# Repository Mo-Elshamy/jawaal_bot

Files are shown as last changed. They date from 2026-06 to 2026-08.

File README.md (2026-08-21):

# Jawbot Autonomous Mobile Robot (AMR)





## 1. Overview
Jawbot is a custom-built Autonomous Mobile Robot (AMR) designed around a differential drive kinematics system. It aims to bridge low-level microcontrollers (Raspberry Pi Pico) with high-level ROS 2 navigation stacks, providing a robust, extensible platform for research, education, and development of mobile robotics applications.

## 2. Key Features
- **Diff-Drive Kinematics:** Fully supported by the ROS 2 `diff_drive_controller` and `joint_state_broadcaster`.
- **Custom Hardware Interface:** Uses a custom `ros2_control` `SystemInterface` to communicate seamlessly with the microcontroller.
- **Real-Time Closed-Loop Control:** Dual-stage friction compensation (breakaway kick & kinetic assist) and PID velocity tracking executed deterministically on the Raspberry Pi Pico at 50Hz.
- **RPLiDAR A1 Integration:** Dedicated ROS 2 node setup for real-time 2D laser scan publishing (`/scan`).
- **2D SLAM & Map Localization:** Parameterized `slam_toolbox` mapping and `AMCL` particle filter localization for precise map-based pose estimation.
- **Nav2 Autonomous Navigation:** Full integration with ROS 2 Nav2 stack featuring Regulated Pure Pursuit, local/global costmaps, velocity smoother, and collision monitor.
- **Simulation Ready:** Full integration with Gazebo (Harmonic) for physics simulation and testing prior to hardware deployment.
- **Modular Architecture:** Packages are neatly decoupled, isolating hardware drivers from kinematics, localization, and navigation.

## 3. System Architecture Stack
Jawbot operates on a decoupled, full-stack architecture:

- **Hardware Layer:** Raspberry Pi Pico (Main MCU), L298N Motor Drivers, Quadrature Encoders, and RPLiDAR A1 M8. Handles real-time dual-stage friction compensation, interrupt-driven sensor tracking, and 2D laser range scanning.
- **Software Layer:** Runs on Ubuntu 24.04 with ROS 2 Jazzy. Manages high-level velocity commands (`cmd_vel`), TF trees, state publishing, EKF sensor fusion (50Hz), AMCL localization, `slam_toolbox` mapping, and Nav2 path execution (`velocity_smoother` & `collision_monitor`).
- **Control Bridge:** A robust, non-blocking ASCII Serial Protocol over `/dev/ttyACM0` connecting the Linux environment to the hardware.

*For a detailed deep-dive into the control architecture, firmware design, dual-stage friction compensation, and serial protocol, please see the [Control Architecture Documentation](jawbot_hardware/Control_Arc.md).*
*For step-by-step procedures on calibrating odometry (wheel radius, track width, encoder ticks) and IMU offsets (GY-87), please see the [Sensor & Odometry Calibration Guide](SENSOR_CALIBRATION.md).*
*For tuning guidelines, parameter definitions, and troubleshooting common navigation behaviors, please see the [Nav2 Calibration Guide](NAV2_CALIBRATION.md).*

## 4. Repository Structure
The project is divided into several focused ROS 2 packages:

- **`jawbot_description`**: Contains the URDF, Xacro macros, and 3D meshes defining the robot's physical properties.
- **`jawbot_hardware`**: The core C++ `ros2_control` hardware plugin, Linux serial communication drivers, firmware (`RobotJoint` dual-stage friction logic), and RPLiDAR launch configuration.
- **`jawbot_gazebo`**: Launch files and world definitions for Gazebo simulation.
- **`jawbot_bringup`**: Orchestrates the launch sequences, starting the robot state publisher, controller manager, and spawning controllers.
- **`jawbot_localization`**: Extended Kalman Filter (EKF) state estimation fusing raw IMU data and wheel odometry at 50Hz, plus standalone AMCL launch configurations.
- **`jawbot_navigation`**: Configuration files for ROS 2 Nav2, AMCL parameters, `slam_toolbox` params, navigation launch scripts, and saved maps.

## 5. Prerequisites & Dependencies
- **OS:** Ubuntu 24.04 LTS
- **ROS 2:** Jazzy Jalisco
- **Build Tool:** `colcon`
- **Dependencies:**
  - `ros2_control` & `ros2_controllers`
  - `robot_state_publisher`
  - `xacro`
  - `gazebo_ros_pkgs`
  - `robot_localization`
  - `rplidar_ros`
  - `slam_toolbox`
  - `nav2_bringup`
  - `nav2_amcl`
  - `nav2_map_server`
  - `nav2_lifecycle_manager`

### Hardware Requirements
- Host computer / SBC running Linux
- Raspberry Pi Pico (flashed with `jawbot_pico` firmware)
- USB Serial connection to the Pico (e.g., `/dev/ttyACM0`)

## 6. Simulation Deployment Guide

This section outlines how to set up, build, and run the robot in a simulated Gazebo environment on your local development machine.

### Step 1: Set Up Workspace & Clone Packages
```bash
mkdir -p ~/test_ws/src
cd ~/test_ws/src
# Clone the jawbot repository here
```

### Step 2: Install Dependencies
```bash
cd ~/test_ws
source /opt/ros/jazzy/setup.bash
rosdep install --from-paths src --ignore-src -r -y
```

### Step 3: Compile the Workspace
```bash
colcon build --symlink-install
```

### Step 4: Sourcing and Running the Simulation
```bash
source install/setup.bash
ros2 launch jawbot_gazebo gazebo.launch.py
```

### Teleoperation
To drive the robot in the simulation, open a new terminal and run:
```bash
source /opt/ros/jazzy/setup.bash
ros2 run teleop_twist_keyboard teleop_twist_keyboard
```

## 7. Real Hardware Deployment Guide (Wireless / Pi Mode)

This section outlines how to deploy, compile, and run the production robotics stack directly on the robot's onboard Single Board Computer (SBC) over a wireless network link.

### Prerequisites
* The SBC must be powered, connected to the same local Wi-Fi subnet as your development laptop, and have SSH enabled.
* The low-level microcontroller (e.g., Pi Pico, ESP32) must be physically attached to the SBC via a USB data cable.
* ROS 2 must already be natively installed on the SBC operating system.

---

### Step 1: Establish Remote Connection (SSH)
Open a terminal window on your laptop and log into the robot’s wireless terminal interface. Replace `<username>` and `<hostname>` with your robot's configured credentials:

```bash
ssh <username>@<hostname>.local
# (Alternatively, connect using the robot's direct IP address: ssh <username>@<ip_address>)

```

### Step 2: Set Up Workspace & Clone Packages

Create a dedicated developer workspace, navigate to its source folder, and pull down your robot controller repositories:

```bash
# Create the workspace directory structure
mkdir -p ~/robot_ws/src
cd ~/robot_ws/src

# Clone your robot code repositories
git clone <your_repository_git_url> .

```

### Step 3: Configure Hardware Access Permissions

Linux secures hardware serial lines by default. Grant your user account permanent permission to read and write data over the physical USB serial port interfaces:

```bash
# Add the active user to the dialout hardware communication group
sudo usermod -aG dialout $USER

# Force-apply the group updates without requiring a system reboot
newgrp dialout
# (Verify your microcontroller is registered by running ls /dev/ttyACM* or ls /dev/ttyUSB*)

```

### Step 4: Resolve Dependencies Automatically

Scan the cloned repository package definitions (`package.xml`) and pull down any missing drivers, middleware, or operational plugins required by the hardware control loops:

```bash
cd ~/robot_ws
sudo apt update
rosdep update
rosdep install --from-paths src --ignore-src -y --rosdistro $ROS_DISTRO

```

### Step 5: Compile the Workspace

Compile the package nodes and hardware interface plugins directly on the single-board computer architecture. We use symbolic link maps to allow modification of launch and config files without re-building:

```bash
cd ~/robot_ws
colcon build --symlink-install

```

### Step 6: Sourcing and Running the Robot Bringup

Load the freshly compiled package targets into your environment variables and execute the master real-hardware orchestrator launch file:

```bash
# Source the workspace setup profile
source install/setup.bash

# Run the master bringup launch file
ros2 launch jawbot_bringup real_bringup.launch.py

```

### Teleoperation

Once the robot is running, you can teleoperate it from a new SSH terminal or a connected laptop (provided `ROS_DOMAIN_ID` is set correctly):

```bash
ros2 run teleop_twist_keyboard teleop_twist_keyboard

```

### Step 7: Dynamic PID Controller Tuning

To achieve smooth and accurate movements, Jawbot utilizes an embedded C++ node to dynamically tune the Pi Pico's motor PID loops mid-flight.

**1. Launch the Visualization Tools:**
On your local development laptop, run the dynamic parameter GUI and the real-time plotter tool:

```bash
# Terminal 1: Open the parameter sliders
ros2 run rqt_reconfigure rqt_reconfigure

# Terminal 2: Open the velocity plotter pre-loaded with left/right wheel velocity topics
ros2 run rqt_plot rqt_plot /joint_states/velocity[0] /joint_states/velocity[1]

```

**2. Tune the Robot Mid-Flight:**

* Safely place the robot on an elevated block so the wheels can spin freely in the air.
* Use your teleop terminal to send a constant velocity command (e.g., driving straight forward).
* In `rqt_reconfigure`, select the `jawbot_pid_tuner` node. Use the sliders to dynamically adjust `motor_kp`, `motor_ki`, and `motor_kd`.
* Watch `rqt_plot` (monitoring the `/joint_states` velocity data) to ensure the actual wheel speed smoothly converges on your target speed without violent oscillations.

> ⚠️ **Common Pitfall — Plotting Array Fields in `rqt_plot`:**  
> Unlike RViz, `rqt_plot` cannot plot entire ROS message structs; it requires single numerical variables (floats/integers). Typing `/joint_states` into the Topic bar will show nothing because it is a complex message containing arrays.  
>  
> **The Fix:** In the `rqt_plot` text bar, type the exact numeric field index and click the green **`+`** button:  
> - **Left Wheel Velocity:** `/joint_states/velocity[0]`  
> - **Right Wheel Velocity:** `/joint_states/velocity[1]`  
> - **Alternative (Odom Linear Speed):** `/jawbot_base_controller/odom/twist/twist/linear/x`

* Finally, place the robot on the floor and slightly increase `motor_ki` to help the robot push through physical ground friction.

**3. Hardcode and Save the Final Values:**
The `rqt_reconfigure` GUI only overwrites the PID values temporarily in active memory. Once you have found your ideal "Magic Numbers" from the floor test, you must permanently save them to keep the system synchronized on boot:

* **The C++ ROS 2 Interface (The GUI Default):** Open your hardware implementation  file (e.g., `jawbot_hardware_interface.cpp`). Update the starting state variables (`current_kp_`, `current_ki_`, `current_kd_`) so the GUI sliders correctly reflect the Pico's default state the next time you open them.

### Step 8: Sensor & Odometry Calibration

Before deploying high-level navigation stacks (Nav2 / SLAM), ensure your robot's physical kinematics and IMU sensors are properly calibrated to eliminate drift:
* Follow the **[Sensor & Odometry Calibration Guide](SENSOR_CALIBRATION.md)** for step-by-step instructions on calibrating encoder ticks per revolution, effective wheel radius, track width, and GY-87 accelerometer/gyroscope zero-offsets.

---

### Step 9: 2D SLAM Mapping & Map Saving

Jawbot uses `slam_toolbox` in online asynchronous mapping mode coupled with RPLiDAR scan data for high-quality 2D occupancy grid mapping.

#### 1. Launch Hardware Bringup & RPLiDAR
On the robot (or in bringup launch sequence), ensure the real hardware driver and RPLiDAR node are running:
```bash
# Launch master hardware bringup (which launches real hardware interface + RPLiDAR)
ros2 launch jawbot_bringup real_bringup.launch.py
```

#### 2. Launch SLAM Toolbox
Start the SLAM node with the custom `slam_toolbox_params.yaml` configuration:
```bash
ros2 launch jawbot_navigation slam.launch.py
```

#### 3. Teleoperate and Build Map
Drive the robot around the room using keyboard teleop to cover all areas:
```bash
ros2 run teleop_twist_keyboard teleop_twist_keyboard
```

#### 4. Save the Generated Map
Once the occupancy grid map is complete, save the map files (`.pgm` image and `.yaml` metadata) to `jawbot_navigation/maps/`:
```bash
ros2 run nav2_map_server map_saver_cli -f ~/robot_ws/src/jawaal_bot/jawbot_navigation/maps/my_room_1
```

---

### Step 10: Map-Based Localization (AMCL)

Once a map is generated, launch Adaptive Monte Carlo Localization (AMCL) and the map server to localize the robot on the saved map:

```bash
# Launch map_server, amcl, and localization lifecycle manager
ros2 launch jawbot_navigation localization.launch.py map:=src/jawaal_bot/jawbot_navigation/maps/my_room_1.yaml
```

---

### Step 11: Nav2 Autonomous Navigation

To execute full autonomous waypoint tracking and dynamic obstacle avoidance with safety monitoring:

```bash
# 1. Bring up full Nav2 stack (Planner, Controller, Recoveries, Velocity Smoother, Collision Monitor)
ros2 launch jawbot_navigation navigation.launch.py map:=src/jawaal_bot/jawbot_navigation/maps/my_room_1.yaml
```

*For an in-depth parameter guide and calibration manual for Nav2 controller server, costmaps, and collision monitor tuning, refer to the **[Nav2 Calibration Guide](NAV2_CALIBRATION.md)**.*

---

## 8. License & Acknowledgments
- **License:** MIT License
- Designed and built as a modular AMR platform.

Notes:
1- the ticks per revolution of the motor is 988 and need to be configured in both jawbot_ros2_control.urdf.xacro and jawbot_pico.ino files
2- the pid params must be set in the jawbot_hardware_cpp and jaw.ino file

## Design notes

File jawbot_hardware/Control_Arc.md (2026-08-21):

# Jawbot Autonomous Mobile Robot: Control Architecture Documentation

This document outlines the full-stack control architecture for the Jawbot AMR. The system uses a modular, decoupled approach that separates high-level ROS 2 kinematic planning from low-level deterministic motor control, bridged by a robust serial communication layer.

---

## Part 1: Microcontroller Firmware (Raspberry Pi Pico)

### 1.1 Methodology
The Pico acts as a real-time execution slave. The architecture uses Object-Oriented C++ principles, abandoning blocking functions (like `delay()`) in favor of hardware-timed interrupts. The methodology relies on a **50Hz Hardware Timer** to execute PID velocity math, paired with **Hardware Interrupt Service Routines (ISRs)** to capture quadrature encoder pulses instantly. It features a **Dual-Stage Friction Compensation and Feedforward System**:
1. **Static Breakaway Kick (`STATIC_BREAKAWAY = 38.0%`):** Provides an initial power boost when starting from low speeds ($<0.25$ rad/s) to overcome static mechanical friction (stiction).
2. **Kinetic Assist (`KINETIC_ASSIST = 33.0%`):** Tapers down to a steady rolling offset once the wheels are in motion.
3. **Feedforward Voltage Scaling (`KV_FEEDFORWARD = 3.3`):** Scales PWM effort proportionally with target velocity for rapid transient response.
4. **Hard Stop & Integral Reset:** Instantly resets PID integral memory (`pid_.reset()`) and zeros motor output when target velocity is zero ($<0.01$ rad/s) to eliminate post-stop wheel creep/oscillations.

### 1.2 Files and Directory
| File Path | Description |
| :--- | :--- |
| `jawbot_pico.ino` | Main dispatcher, hardware timer setup, and communication heartbeat. |
| `L298N.h/.cpp` | Actuator physical layer (PWM and Direction logic). |
| `WheelEncoder.h/.cpp` | Sensor physical layer (Interrupt-driven quadrature tracking). |
| `gy87_driver.h/.cpp` | Sensor physical layer (I2C communication with GY-87 IMU module). |
| `pid.h/.cpp` | Mathematical engine for closed-loop velocity tracking. |
| `RobotJoint.h/.cpp` | Abstraction layer wrapping Motor, Encoder, PID, dual-stage friction offset, and feedforward logic. |

### 1.3 Classes and Functions
| Class | Function | Description |
| :--- | :--- | :--- |
| **`L298N`** | `init()`, `setSpeed()` | Configures GPIOs and maps velocity to PWM signals. |
| **`WheelEncoder`**| `init()`, `handleInterrupt()`, `getTicks()` | Manages quadrature logic via ISRs and safe tick retrieval. |
| **`GY87`** | `init()`, `update()` | Initializes I2C bypass for MPU6050 and HMC5883L, and populates IMU struct with scaled accelerometer, gyroscope, and magnetometer data. |
| **`PIDController`**| `compute()`, `setGains()` | Executes velocity tracking math and supports live gain tuning. |
| **`RobotJoint`** | `executeControlLoop()` | Cascades logic: Encoder $\to$ Velocity Calc $\to$ Hard Stop Check $\to$ PID $\to$ Feedforward & Dual-Stage Friction Compensation $\to$ Saturation Limiter $\to$ Motor PWM. |

---

## Part 2: ROS 2 Control (Hardware Interface Plugin)

### 2.1 Methodology
This layer runs on the Linux SBC using the `ros2_control` framework. It acts as a translator between ROS 2 joint state/command interfaces and the low-level serial protocol. It runs as a `SystemInterface` plugin loaded by the `controller_manager`, ensuring the robot's hardware state is synchronized with the URDF model. This includes exposing wheel joint states as well as **IMU Sensor State Interfaces** (accelerometer, gyroscope, and magnetometer) for the `imu_sensor_broadcaster`. Additionally, it hosts an embedded parameter node allowing for **Dynamic PID Tuning** mid-flight via `rqt_reconfigure`.

### 2.2 Files and Directory
| File Path | Description |
| :--- | :--- |
| `include/jawbot_hardware/interface.hpp` | Interface declarations and lifecycle hooks. |
| `src/jawbot_hardware_interface.cpp` | Implementation of `read()`/`write()` loops and serial translation. |
| `jawbot_hardware.xml` | Plugin registration file for `pluginlib`. |

### 2.3 Classes and Functions
| Class | Function | Description |
| :--- | :--- | :--- |
| **`JawbotHardwareInterface`** | `on_init()` | Parses hardware URDF parameters and initializes state arrays. |
| | `read()` | Ingests serial telemetry and calculates joint velocity via timestamps. |
| | `write()` | Formats target velocities into string commands for the microcontroller. |
| | `on_activate()` | Lifecycle hook: Initializes port and performs safety zeroing of motors. |
| | (Embedded Node) | A background thread (`tune_thread_`) listens for `rqt_reconfigure` parameter updates and syncs them to the Pico. |

---

## Part 3: Serial Communication Layer

### 3.1 Methodology
A **Non-Blocking ASCII Serial Protocol** bridge. This layer ensures robust cross-process communication between Linux and the Pico. It features a watchdog mechanism that monitors command latency; if communication stops (e.g., node crash), the firmware autonomously brakes the robot for safety. The protocol multiplexes high-frequency wheel telemetry with periodic IMU (GY-87) sensor data packets.

### 3.2 Files and Directory
| File Path | Description |
| :--- | :--- |
| `include/jawbot_hardware/serial_comms.hpp` | POSIX Linux serial driver header. |
| `src/serial_comms.cpp` | Raw termios setup and non-blocking read/write implementation. |
| `SerialProtocol.h/.cpp` (Pico) | Parsing logic, telemetry formatting, and watchdog timers. |

### 3.3 Classes and Functions
| Class | Function | Description |
| :--- | :--- | :--- |
| **`SerialComms` (Linux)** | `connect()`, `read_msg()`, `write_msg()` | Manages Linux file descriptors and non-blocking serial I/O. |
| **`SerialProtocol` (Pico)** | `processIncoming()`, `sendTelemetry()` | Parses ASCII commands (`m`, `p`) and sends heartbeat telemetry (both standard wheel-only and overloaded IMU data versions). |
| | `getLastCommandTime()` | Used by the main firmware to monitor watchdog status and blink status LEDs. |

---

## Part 4: Localization & Nav2 Autonomous Navigation

### 4.1 AMCL & Map-Based Pose Estimation
- **Map Server:** Loads static 2D occupancy grid maps (`.yaml`/`.pgm`) generated via `slam_toolbox`.
- **AMCL (Adaptive Monte Carlo Localization):** Uses likelihood field range measurement modeling with differential motion model updates to estimate robot pose (`map` $\to$ `odom` transform).

### 4.2 Nav2 Architecture Pipeline
- **BT Navigator (`bt_navigator`):** Orchestrates high-level goal navigation via ROS 2 Behavior Trees (`NavigateToPose`).
- **Global Planner (`planner_server`):** Computes global paths across the environment map using A* search (`NavfnPlanner`).
- **Local Controller (`controller_server`):** Executes path tracking using **Regulated Pure Pursuit Controller**, featuring rotate-to-heading, velocity-scaled lookahead distance, and cost-regulated speed reduction.
- **Costmaps (`local_costmap` & `global_costmap`):** Dynamic 2D obstacle marking/clearing from RPLiDAR scans (`/scan`) combined with inflation cost scaling.
- **Velocity Smoother (`velocity_smoother`):** Filters and constrains velocity/acceleration ramps before passing commands to hardware interfaces.
- **Collision Monitor (`collision_monitor`):** Real-time safety layer enforcing active emergency stop bounding polygons (`PolygonStop` circle radius 0.17m) directly on scan sensor streams.

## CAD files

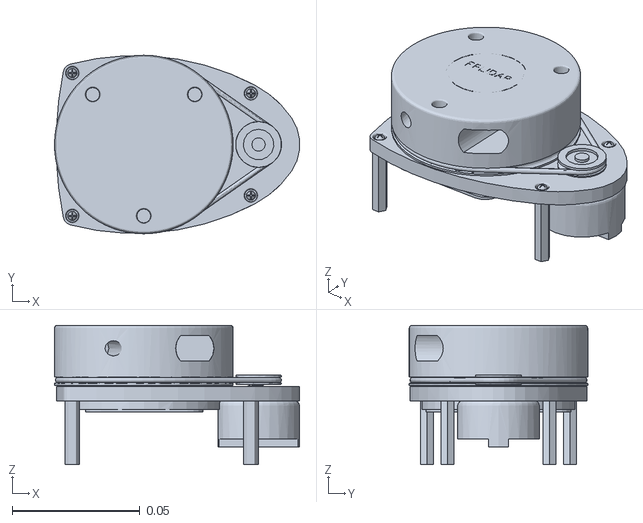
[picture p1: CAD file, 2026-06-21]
jawbot_gazebo/models/jawbot/meshes/lidar_link.STL
0.096 x 0.07 x 0.0546

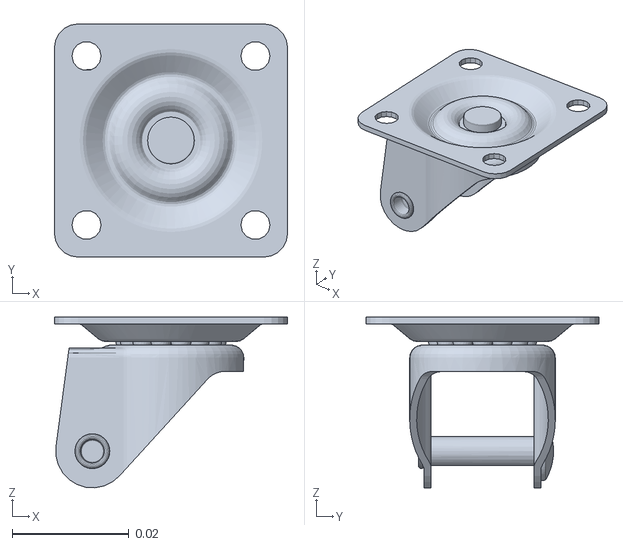
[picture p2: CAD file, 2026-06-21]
jawbot_gazebo/models/jawbot/meshes/caster_front_link.STL
0.04 x 0.04 x 0.0293

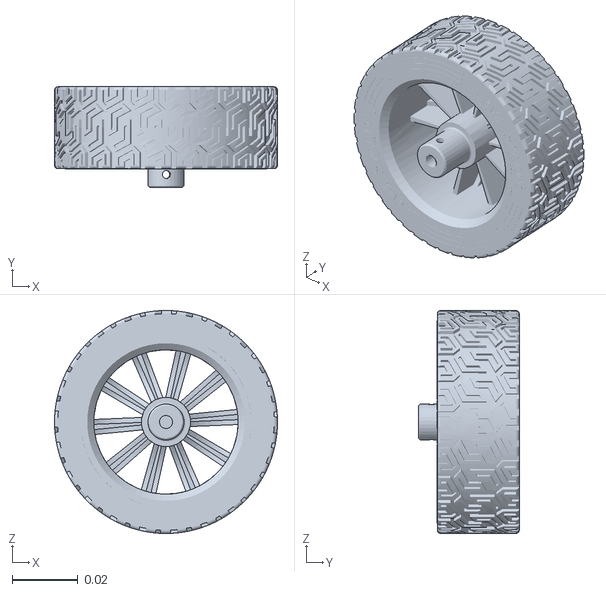
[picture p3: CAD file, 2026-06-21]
jawbot_gazebo/models/jawbot/meshes/left_wheel_link.STL
0.068 x 0.0308 x 0.068

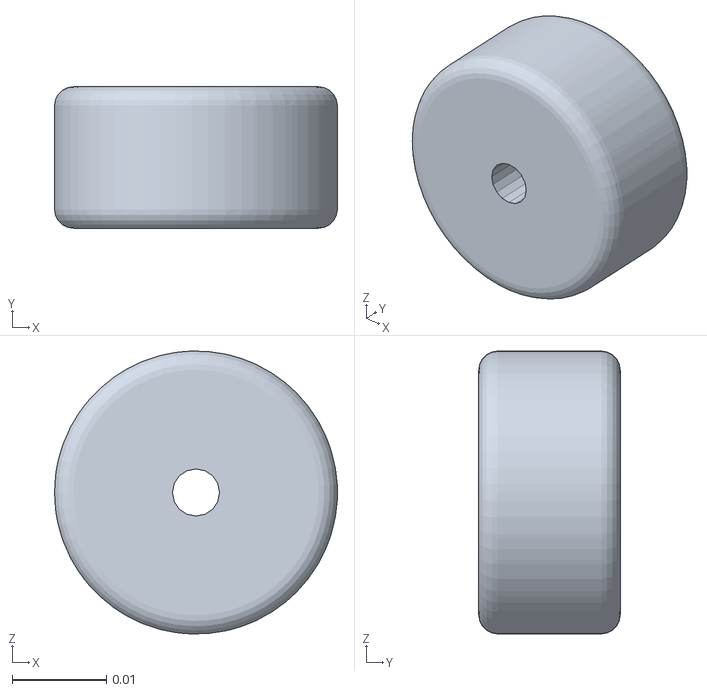
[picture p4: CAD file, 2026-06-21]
jawbot_gazebo/models/jawbot/meshes/caster_front_wheel_link.STL
0.03 x 0.015 x 0.03

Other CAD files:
jawbot_gazebo/models/jawbot/meshes/caster_back_link.STL
jawbot_gazebo/models/jawbot/meshes/right_wheel_link.STL
jawbot_gazebo/models/jawbot/meshes/caster_back_wheel_link.STL

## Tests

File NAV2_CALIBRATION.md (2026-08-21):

# Nav2 Parameter & Calibration Guide (`nav2_params.yaml`)

This guide explains the parameters in `jawbot_navigation/config/nav2_params.yaml`, their physical effects on the **Jawbot AMR**, and common real-world calibration scenarios with recommended solutions.

---

## 1. Parameter Overview & Effects

### 1. AMCL (`amcl`)
| Parameter | Default Value | Function & Physical Effect |
| :--- | :--- | :--- |
| `min_particles` / `max_particles` | `500` / `2000` | Controls particle filter population density. Higher numbers increase localization resilience during aggressive turns but increase CPU usage. |
| `alpha1` to `alpha4` | `0.2` | Expected noise parameters in differential motion model (rotation from rotation, rotation from translation, translation from translation, translation from rotation). Higher values increase particle spread during movement. |
| `update_min_d` / `update_min_a` | `0.1m` / `0.1 rad` | Minimum linear displacement or rotation required to trigger a particle filter update step. Keeps localization idle while stationary. |
| `laser_model_type` | `likelihood_field` | Standard scan matching model. Fast and robust for indoor lidar mapping. |
| `z_hit` / `z_rand` | `0.8` / `0.05` | Weight given to scan hits vs. random noise scans. |

### 2. Local Controller (`controller_server` & `RegulatedPurePursuitController`)
| Parameter | Default Value | Function & Physical Effect |
| :--- | :--- | :--- |
| `desired_linear_vel` | `0.25 m/s` | Maximum target cruising speed along paths. |
| `lookahead_dist` | `0.4 m` | Standard distance along global path where the pure pursuit controller places its target point. |
| `min_lookahead_dist` / `max_lookahead_dist` | `0.2m` / `0.6m` | Bounds for dynamic lookahead scaling. Shorter lookaheads tighten cornering; longer lookaheads smooth out straight paths. |
| `use_rotate_to_heading` | `true` | Enables turning-in-place when starting a path or reaching a goal if heading error is large. Prevents wide curved arcs when initiating movements. |
| `rotate_to_heading_min_angular_vel` | `1.2 rad/s` | Minimum angular speed threshold during rotate-to-heading to overcome wheel stiction and ground friction. |
| `use_cost_regulated_linear_velocity_scaling` | `true` | Automatically slows down linear speed when operating close to high-cost inflation zones (near obstacles). |

### 3. Global Planner (`planner_server` & `NavfnPlanner`)
| Parameter | Default Value | Function & Physical Effect |
| :--- | :--- | :--- |
| `use_astar` | `true` | Switches planner search algorithm from Dijkstra to A*. Reduces path computation latency. |
| `allow_unknown` | `true` | Allows global path planning through unmapped/unexplored space. |
| `tolerance` | `0.2m` | Distance tolerance around requested goal position to find a valid free cell if goal is blocked. |

### 4. Costmaps (`local_costmap` & `global_costmap`)
| Parameter | Default Value | Function & Physical Effect |
| :--- | :--- | :--- |
| `robot_radius` | `0.15m` | Circular collision boundary around robot base center (`base_footprint`). |
| `inflation_radius` | `0.35m` | Buffer zone around obstacles where traversal cost decreases exponentially outwards. |
| `cost_scaling_factor` | `3.0` | Exponential decay rate of inflation cost. Higher values cause sharp cost drop-offs near obstacles; lower values create wider safety corridors. |
| `raytrace_max_range` / `obstacle_max_range` | `3.0m` / `2.5m` (Local) | Range bounds for clearing vs. inserting obstacle points into local costmap from RPLiDAR scans. |

### 5. Velocity Smoother (`velocity_smoother`)
| Parameter | Default Value | Function & Physical Effect |
| :--- | :--- | :--- |
| `max_velocity` | `[0.25, 0.0, 1.5]` | Max linear velocity ($X$), lateral velocity ($Y$), and angular velocity ($Z$). |
| `min_velocity` | `[-0.10, 0.0, -1.5]` | Min reverse velocity and angular limits. |
| `max_accel` / `max_decel` | `[0.5, 0.0, 3.2]` / `[-0.5, 0.0, -3.2]` | Acceleration and deceleration constraints ($m/s^2$ and $rad/s^2$) to prevent wheel slip and mechanical jerks. |

### 6. Collision Monitor (`collision_monitor`)
| Parameter | Default Value | Function & Physical Effect |
| :--- | :--- | :--- |
| `cmd_vel_in_topic` / `cmd_vel_out_topic` | `cmd_vel_smoothed` $\to$ `cmd_vel` | Intercepts smoothed velocity commands and halts output if LIDAR scan enters safety polygon. |
| `PolygonStop.radius` | `0.17m` | Emergency stop circle radius surrounding the 0.15m footprint. |
| `min_points` | `3` | Number of LIDAR range hits inside the polygon required to trigger an immediate zero-velocity halt. |

---

## 2. Common Calibration Situations & Recommendations

### Situation 1: The Robot Oscillates or Bounces Back and Forth Along Narrow Hallways
- **Symptom:** The robot sways side-to-side repeatedly or struggles to follow a straight path.
- **Cause:** Lookahead distance is too short, or inflation costs drop off too slowly.
- **Recommended Tuning:**
  1. Increase `lookahead_dist` from `0.4` to `0.5m` or `0.6m`.
  2. Increase `cost_scaling_factor` in both costmaps from `3.0` to `5.0` to steepen cost falloff near walls.

### Situation 2: The Robot Fails to Rotate in Place When Navigating to a New Goal
- **Symptom:** The robot whines or stalls when attempting to turn in place towards a path segment.
- **Cause:** `rotate_to_heading_min_angular_vel` is lower than the physical ground friction threshold.
- **Recommended Tuning:**
  1. Increase `rotate_to_heading_min_angular_vel` in `controller_server` (e.g., from `1.2` to `1.4` or `1.5 rad/s`).
  2. Ensure the firmware dual-stage friction compensation (`STATIC_BREAKAWAY` in `RobotJoint.cpp`) is set appropriately.

### Situation 3: Sudden Emergency Stops Near Doorways or Tight Spaces
- **Symptom:** Robot freezes near narrow door frames even though global planner showed a valid path.
- **Cause:** Inflation radius is too large or collision monitor polygon footprint (`PolygonStop`) is oversized for the clearance width.
- **Recommended Tuning:**
  1. Reduce `inflation_radius` from `0.35m` to `0.25m` - `0.30m`.
  2. Verify `PolygonStop.radius` in `collision_monitor` is set just outside the robot radius (e.g. `0.17m` for `0.15m` robot radius).

### Situation 4: AMCL Particles Spread Out and Robot Loses Map Tracking During Fast Turns
- **Symptom:** In RViz, laser scans mismatch map walls after rapid rotational maneuvers.
- **Cause:** Motion noise parameters (`alpha1` / `alpha2`) are underestimating actual wheel slippage, or AMCL update rate is too slow.
- **Recommended Tuning:**
  1. Increase `alpha1` (rotational noise from rotation) from `0.2` to `0.3`.
  2. Decrease `update_min_a` in AMCL from `0.1` to `0.05 rad` for higher frequency orientation updates.

### Situation 5: Mechanical Jerking and Motor Tripping on Acceleration
- **Symptom:** Current spikes occur or motor driver resets during rapid speed transitions.
- **Cause:** Acceleration limits in `velocity_smoother` exceed motor drive torque limits.
- **Recommended Tuning:**
  1. Reduce `max_accel` in `velocity_smoother` from `0.5` to `0.3 m/s²`.
  2. Reduce angular acceleration `max_accel[2]` from `3.2` to `2.0 rad/s²`.

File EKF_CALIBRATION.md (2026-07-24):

# 📊 EKF Tuning & Troubleshooting Guide (`robot_localization`)

This reference playbook provides guidance for tuning the Extended Kalman Filter (`ekf_filter_node`) parameters in `jawbot_localization` when observing unexpected robot state estimation, drift, or jitter.

---

## 🎯 High-Level Tuning Philosophy
EKF state estimation mathematically balances trust between physical kinematic models and live sensor payloads:
> *"Trust wheel encoders for forward velocity ($v_x$), trust the IMU gyroscope for angular rotation ($\omega_z$), and suppress stationary high-frequency sensor noise."*

---

## 1. Core Mathematical Tuning Parameters

### A. Process Noise Covariance Matrix ($Q$)
* **Location:** `jawbot_localization/config/ekf.yaml` under `process_noise_covariance`.
* **Description:** A $15 \times 15$ diagonal matrix representing uncertainty in the robot's physical motion model between timestep updates across 15 state variables:

$$\text{State} = [x, y, z, \text{roll}, \text{pitch}, \text{yaw}, v_x, v_y, v_z, \omega_{\text{roll}}, \omega_{\text{pitch}}, \omega_{\text{yaw}}, a_x, a_y, a_z]$$

```yaml
# Matrix order: x, y, z, roll, pitch, yaw, vx, vy, vz, vroll, vpitch, vyaw, ax, ay, az
process_noise_covariance: [
  0.05, 0.0,  0.0,  0.0,  0.0,  0.0,  0.0,  0.0,  0.0,  0.0,  0.0,  0.0,  0.0,  0.0,  0.0,
  0.0,  0.05, 0.0,  0.0,  0.0,  0.0,  0.0,  0.0,  0.0,  0.0,  0.0,  0.0,  0.0,  0.0,  0.0,
  # ... (15x15 diagonal matrix)
]
```

* **High $Q$ Values:** Filter assumes physical motion model is uncertain $\rightarrow$ Relies heavily on incoming sensor measurements.
  * *Result:* Fast response to real movement, but higher jitter/noise in `/odom`.
* **Low $Q$ Values:** Filter assumes physical motion model is highly accurate $\rightarrow$ Relies strictly on model integration.
  * *Result:* Extremely smooth `/odom` data, but noticeable lag or overshoot during rapid acceleration/turns.

---

### B. Sensor Measurement Covariance ($R$)
* **Location:** Configured inside sensor drivers/broadcasters (e.g. `jawbot_bringup/config/jawbot_controllers.yaml` for `imu_broadcaster`).
* **Description:** Quantifies expected noise levels for raw sensor data streams.

```yaml
imu_broadcaster:
  ros__parameters:
    sensor_name: "imu_sensor"
    frame_id: "imu_link"
    static_covariance_angular_velocity: [0.001, 0.0, 0.0, 0.0, 0.001, 0.0, 0.0, 0.0, 0.001]
    static_covariance_linear_acceleration: [0.001, 0.0, 0.0, 0.0, 0.001, 0.0, 0.0, 0.0, 0.001]
```

* **Higher $R$ Value:** Filter treats sensor measurements as noisier, smoothing out spikes.
* **Lower $R$ Value:** Filter treats sensor data as high precision, trusting raw values immediately.

---

### C. Outlier Rejection Thresholds (`*_reject_threshold`)
* **Location:** `jawbot_localization/config/ekf.yaml`.
* **Description:** Safety gates based on Mahalanobis Distance (statistical distance of new measurements from expected state).

```yaml
odom0_reject_threshold: 5.0
imu0_reject_threshold: 3.0
```

* **How it works:** If a sensor measurement spikes unexpectedly (e.g. electrical noise or wheel bump), the EKF rejects the sample entirely instead of corrupting the robot's pose estimate.

---

## 2. Practical Tuning & Symptom Matrix

| Symptom | Root Cause | Recommended Fix |
|---|---|---|
| **`/odom` pose is jittery/shaking when stationary** | Process noise ($Q$) set too high or sensor noise covariance ($R$) set too low. | • Decrease $Q$ for $v_x$ and $\omega_z$ in `ekf.yaml`.<br>• Increase static covariance ($R$) in `jawbot_controllers.yaml`. |
| **Robot turns in real life, but `/odom` orientation lags behind** | Filter is forcing the robot to follow the linear motion model too strictly. | • Increase $Q$ value for yaw velocity ($\omega_z$) or yaw acceleration ($a_z$) in `ekf.yaml`. |
| **Wheels slip on smooth floors causing position drift** | Filter relies excessively on wheel speed ($v_x$) during slippage. | • Decrease $Q$ for wheel speed $v_x$.<br>• Increase reliance on IMU $x$-acceleration ($a_x$). |
| **Sudden position jump/teleporting in RViz** | Spurious sensor artifact passed into the filter without rejection. | • Lower `imu0_reject_threshold` or `odom0_reject_threshold` (e.g., from `5.0` to `3.0`). |

---

## 3. Quick-Reference Checklist for Odd Behavior

1. **Verify Static State:** Stop the robot. Run `ros2 topic echo /odom`. Position and orientation should not drift or jitter.
2. **Verify Gyro Yaw Response:** Rotate the robot by hand $90^\circ$. Check if `/odom` orientation updates in real-time without delay.
3. **Verify Rejection Logs:** Check terminal output of `ekf_node` for warnings regarding rejected measurements.

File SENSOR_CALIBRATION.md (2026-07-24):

# 🤖 Jawbot Sensor & Odometry Calibration Guide

Accurate sensor readings and odometry are the foundation of the entire ROS 2 Navigation Stack (Nav2) and Extended Kalman Filter (EKF). If the robot's physical movement does not match its software estimates or if sensors drift while static, SLAM maps will warp, obstacles will duplicate, and state estimation will fail.

This guide outlines the standard operating procedures for calibrating both the **Differential Drive Odometry** and the **GY-87 IMU (MPU6050/HMC5883L)**.

> 💡 **Looking for EKF filter tuning?** Refer to the **[EKF Tuning & Troubleshooting Guide](jawbot_localization/EKF_CALIBRATION.md)** for process noise ($Q$), measurement noise ($R$), and outlier rejection threshold tuning.

---

## 📋 Table of Contents
1. [Part 1: Differential Drive Odometry Calibration](#-part-1-differential-drive-odometry-calibration)
   - [Phase 1: Base Encoder Calibration (Ticks Per Rev)](#-phase-1-base-encoder-calibration-ticks-per-revolution)
   - [Phase 2: Linear Calibration (Wheel Radius)](#-phase-2-linear-calibration-effective-wheel-radius)
   - [Phase 3: Angular Calibration (Track Width)](#-phase-3-angular-calibration-track-width--wheel-separation)
2. [Part 2: GY-87 IMU Calibration (MPU6050)](#-part-2-gy-87-imu-calibration-mpu6050)
   - [Step 1: Standalone Calibration Script](#step-1-run-the-standalone-calibration-script)
   - [Step 2: Applying Offsets to Firmware](#step-2-apply-the-offsets-to-your-architecture)
3. [Troubleshooting & Pro-Tips](#-troubleshooting--pro-tips)

---

# 🚜 Part 1: Differential Drive Odometry Calibration

## 🛠 Prerequisites
* Robot is fully assembled with operating mass (battery, payload) attached.
* Low-level hardware interface (`ros2_control` + micro-controller) is running.
* PID velocity controllers are fully tuned.
* Access to a measuring tape and floor tape.

---

## 🟢 Phase 1: Base Encoder Calibration (Ticks Per Revolution)
**Objective:** Guarantee the micro-controller is perfectly converting raw magnetic pulses into standard radians.

### The Test (Suspended)
1. **Elevate the robot** so the drive wheels are suspended in the air (no ground friction).
2. Place a piece of tape on the wheel and a matching alignment mark on the chassis.
3. Open a terminal and monitor the raw joint states:
   ```bash
   ros2 topic echo /joint_states
   ```
4. Physically rotate the wheel by hand exactly **10 full revolutions** forward.

### The Math
* **Expected Value:** 10 revolutions × 2π = **62.8318 radians**.
* If the terminal reads negative (e.g., `-62.83`), the encoder Phase A/B wires are swapped. Physically swap them on the micro-controller.
* If the magnitude is wrong, calculate your true `ticks_per_rev` for your firmware:

> **Formula:**  
> `Corrected Ticks Per Rev = Current Ticks Per Rev * (Actual Radians Read / 62.8318)`

**Action:** Flash the new integer to the micro-controller and repeat until 10 spins equals `~62.83` radians.

---

## 🔵 Phase 2: Linear Calibration (Effective Wheel Radius)
**Objective:** Correct for tire compression under the robot's weight.

### The Test (On the Floor)
1. Place the robot on its primary operating surface (carpet, tile, etc.).
2. Mark the starting position of the front bumper with tape.
3. Restart the ROS 2 bringup to zero out the odometry frame.
4. Launch a teleop node:
   ```bash
   ros2 run teleop_twist_keyboard teleop_twist_keyboard
   ```
5. Drive the robot perfectly straight forward.
6. Stop the robot, place a second piece of tape at the new bumper position, and measure the exact **Physical Distance** with a tape measure (e.g., `1.00 meters`).
7. Check what the software *thinks* happened:
   ```bash
   ros2 topic echo /odom --once
   ```
   *Look at `pose.pose.position.x` for the **Software Distance**.*

### The Math
> **Formula:**  
> `New Wheel Radius = Old Wheel Radius * (Physical Distance / Software Distance)`

**Action:** Update the `wheel_radius` parameter in your `controllers.yaml` file.

---

## 🟣 Phase 3: Angular Calibration (Track Width / Wheel Separation)
**Objective:** Correct for the true physical distance between the wheels, accounting for wheel thickness and turning friction.

### The Test (On the Floor)
1. Place a long piece of tape on the floor perfectly aligned with the left side of the robot.
2. Launch RViz to visualize the software's odometry frame:
   ```bash
   rviz2
   ```
   *Set Fixed Frame to `odom` and add the RobotModel/TF display.*
3. Use the teleop node to spin the robot in place.
4. **Watch RViz, not the physical robot.** Spin until the *virtual* robot in RViz completes exactly **one 360-degree rotation** and faces perfectly straight again.
5. Look at the *physical* robot on the floor:
   * Measure the physical angle it actually rotated relative to your starting tape line using a protractor.
   * If it spun past the line, it over-rotated (e.g., 375°). If it stopped short, it under-rotated (e.g., 345°).

### The Math
> **Formula:**  
> `New Track Width = Old Track Width * (Software Angle [360] / Physical Angle Measured)`

**Action:** Update the `wheel_separation` parameter in your `controllers.yaml` file.

---

# 🧭 Part 2: GY-87 IMU Calibration (MPU6050)

Calibrating the static offsets for the accelerometer and gyroscope makes a night-and-day difference in your ROS 2 Extended Kalman Filter (robot_localization). 

When the robot is sitting perfectly still:
* **Gyroscope** should report exactly `0.0 rad/s` on all axes.
* **Accelerometer** should report `0.0 m/s²` on X and Y, and `9.80665 m/s²` (1g of Earth's gravity) on Z.

Because of manufacturing tolerances, it never does. We calculate the difference between what the sensor *actually* reads and what it *should* read, and permanently subtract that error in the C++ driver.

---

### Step 1: Run the Standalone Calibration Script

Open a **brand new sketch** in the Arduino IDE and paste this self-contained script.

> ⚠️ **Critical Rule:** Place the robot on a perfectly flat, level floor. Once you click "Upload," **do not touch the robot or bump the table**. Even tiny vibrations will ruin the calibration.

```cpp
#include <Wire.h>

const uint8_t MPU_ADDR = 0x68;
const float ACCEL_SCALE = 9.80665 / 16384.0;
const float GYRO_SCALE = 0.0174533 / 131.0;

void setup() {
  Serial.begin(115200);
  while (!Serial);

  Wire.setSDA(0);
  Wire.setSCL(1);
  Wire.begin();

  // Wake up the MPU6050
  Wire.beginTransmission(MPU_ADDR);
  Wire.write(0x6B);
  Wire.write(0x00);
  Wire.endTransmission();
  delay(100);

  Serial.println("DO NOT MOVE THE ROBOT.");
  Serial.println("Calibrating in 3 seconds...");
  delay(3000);
  Serial.println("Taking 2000 samples. Please wait...");

  long ax_sum = 0, ay_sum = 0, az_sum = 0;
  long gx_sum = 0, gy_sum = 0, gz_sum = 0;
  int num_samples = 2000;

  for (int i = 0; i < num_samples; i++) {
    Wire.beginTransmission(MPU_ADDR);
    Wire.write(0x3B);
    Wire.endTransmission(false);
    Wire.requestFrom((int)MPU_ADDR, 14, (int)true);

    if (Wire.available() == 14) {
      ax_sum += (int16_t)(Wire.read() << 8 | Wire.read());
      ay_sum += (int16_t)(Wire.read() << 8 | Wire.read());
      az_sum += (int16_t)(Wire.read() << 8 | Wire.read());
      Wire.read(); Wire.read(); // Skip Temperature
      gx_sum += (int16_t)(Wire.read() << 8 | Wire.read());
      gy_sum += (int16_t)(Wire.read() << 8 | Wire.read());
      gz_sum += (int16_t)(Wire.read() << 8 | Wire.read());
    }
    delay(2); // 500Hz sampling rate
  }

  // Calculate raw averages converted directly to ROS standard units
  float ax_avg = ((float)ax_sum / num_samples) * ACCEL_SCALE;
  float ay_avg = ((float)ay_sum / num_samples) * ACCEL_SCALE;
  float az_avg = ((float)az_sum / num_samples) * ACCEL_SCALE;
  
  float gx_avg = ((float)gx_sum / num_samples) * GYRO_SCALE;
  float gy_avg = ((float)gy_sum / num_samples) * GYRO_SCALE;
  float gz_avg = ((float)gz_sum / num_samples) * GYRO_SCALE;

  // Calculate the offsets (Offset = Average Reading - Ideal Reading)
  float ax_off = ax_avg - 0.0;
  float ay_off = ay_avg - 0.0;
  float az_off = az_avg - 9.80665; // Z-axis should read Earth gravity
  
  float gx_off = gx_avg - 0.0;
  float gy_off = gy_avg - 0.0;
  float gz_off = gz_avg - 0.0;

  Serial.println("\n--- CALIBRATION COMPLETE ---");
  Serial.println("Copy and paste these lines into the private section of gy87_driver.h:\n");
  
  Serial.print("const float offset_accel_x = "); Serial.print(ax_off, 5); Serial.println(";");
  Serial.print("const float offset_accel_y = "); Serial.print(ay_off, 5); Serial.println(";");
  Serial.print("const float offset_accel_z = "); Serial.print(az_off, 5); Serial.println(";");
  
  Serial.print("const float offset_gyro_x = "); Serial.print(gx_off, 5); Serial.println(";");
  Serial.print("const float offset_gyro_y = "); Serial.print(gy_off, 5); Serial.println(";");
  Serial.print("const float offset_gyro_z = "); Serial.print(gz_off, 5); Serial.println(";");
}

void loop() {}
```

---

### Step 2: Apply the Offsets to Your Architecture

Once the serial monitor outputs your 6 generated offset values, embed them into the `jawbot_pico` firmware drivers:

**1. Update `gy87_driver.h`**  
Paste the generated lines into the `private:` section of your `GY87` class:

```cpp
class GY87 {
public:
    GY87();
    bool init();
    bool update(IMUData &data);

private:
    const uint8_t MPU_ADDR = 0x68;
    const uint8_t HMC_ADDR = 0x1E;

    const float ACCEL_SCALE = 9.80665 / 16384.0;
    const float GYRO_SCALE = 0.0174533 / 131.0;
    const float MAG_SCALE = 0.0000001; 

    // --- PASTE YOUR GENERATED OFFSETS HERE ---
    const float offset_accel_x = 0.12345; // (Example generated offset)
    const float offset_accel_y = -0.09876;
    const float offset_accel_z = 0.54321;
    const float offset_gyro_x = 0.00123;
    const float offset_gyro_y = -0.00456;
    const float offset_gyro_z = 0.00789;
};
```

**2. Update `gy87_driver.cpp`**  
Locate the conversion math inside `update()` and subtract the offsets:

```cpp
// Convert to ROS standard units AND apply calibration offsets
data.accel_x = (ax * ACCEL_SCALE) - offset_accel_x;
data.accel_y = (ay * ACCEL_SCALE) - offset_accel_y;
data.accel_z = (az * ACCEL_SCALE) - offset_accel_z;

data.gyro_x = (gx * GYRO_SCALE) - offset_gyro_x;
data.gyro_y = (gy * GYRO_SCALE) - offset_gyro_y;
data.gyro_z = (gz * GYRO_SCALE) - offset_gyro_z;
```

Re-flash your Jawbot Pico. Static readings will now report zero velocity/rotation on all axes when stationary.

---

# 🚨 Troubleshooting & Pro-Tips

* **Robot Drifts During Linear Test:** If the robot naturally curves while driving straight, your motors have mismatched friction. Increase the **Integral Gain (Ki)** in your PID controller so it aggressively forces the lagging wheel to match target speed.
* **Command Velocity Watchdog:** If using a script instead of teleop to drive, remember to publish to `/cmd_vel` continuously at 10Hz. Publishing a single command and using `time.sleep()` will trigger the ROS 2 safety watchdog, and the robot will automatically brake after 0.5 seconds.
* **Recalibrate on New Surfaces:** Ground friction heavily influences track width. If moving a robot from smooth concrete to thick carpet, re-run Phase 3 of Odometry Calibration.
* **IMU Mounting Orientation:** Ensure the GY-87 is mounted firmly and aligned with the robot's physical coordinate system (ROS 2 REP 103 standard: X forward, Y left, Z up).

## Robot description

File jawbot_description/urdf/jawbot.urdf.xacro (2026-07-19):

<?xml version="1.0" encoding="utf-8"?>
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

<robot name="jawbot" xmlns:xacro="http://www.ros.org/wiki/xacro">

  <xacro:include filename="jawbot_ros2_control.urdf.xacro" />

  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
  <link name="base_footprint"/>

  <joint name="base_footprint_joint" type="fixed">
    <parent link="base_footprint" />
    <child link="base_link" />
    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
    <origin xyz="0 0 0.060292" rpy="0 0 0" />
  </joint>


  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
  <link name="base_link">
    <inertial>
      <origin xyz="0.00027838 0.00024581 -0.013572" rpy="0 0 0" />
      <mass value="0.51707" />
      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
    </inertial>
    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
  </link>


  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
  <link name="left_wheel_link">
    <inertial>
      <origin xyz="-3.7201E-08 -0.0056934 4.4552E-08" rpy="0 0 0" />
      <mass value="0.033874" />
      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
    </inertial>
    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
  </link>

  <joint name="left_wheel_joint" type="continuous">
    <origin xyz="-0.00079275 0.0925 -0.061542" rpy="0 0 0" />
    <parent link="base_link" />
    <child link="left_wheel_link" />
    <axis xyz="0 1 0" />
  </joint>


  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
  <link name="right_wheel_link">
    <inertial>
      <origin xyz="-3.0238E-09 0.0068146 -5.7962E-08" rpy="0 0 0" />
      <mass value="0.033874" />
      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
    </inertial>
    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
  </link>

  <joint name="right_wheel_joint" type="continuous">
    <origin xyz="-0.00079275 -0.095321 -0.061542" rpy="0 0 0" />
    <parent link="base_link" />
    <child link="right_wheel_link" />
    <axis xyz="0 1 0" />
  </joint>


  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
  <link name="caster_front_link">
    <inertial>
      <origin xyz="-0.0033534 0.00028383 -0.0012173" rpy="0 0 0" />
      <mass value="0.0048487" />
      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
    </inertial>
    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
  </link>

  <joint name="caster_front_joint" type="continuous">
    <origin xyz="0.079207 -0.00085033 -0.063942" rpy="0 0 0" />
    <parent link="base_link" />
    <child link="caster_front_link" />
    <axis xyz="0 0 1" />
  </joint>

  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
  <link name="caster_front_wheel_link">
    <inertial>
      <origin xyz="0 -1.1102E-16 0" rpy="0 0 0" />
      <mass value="0.010151" />
      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
    </inertial>
    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
  </link>

  <joint name="caster_front_wheel_joint" type="continuous">
    <origin xyz="-0.0135 0.0002 -0.0166" rpy="0 0 0" />
    <parent link="caster_front_link" />
    <child link="caster_front_wheel_link" />
    <axis xyz="0 1 0" />
  </joint>


  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
  <link name="caster_back_link">
    <inertial>
      <origin xyz="-0.0033534 0.00028383 -0.0012173" rpy="0 0 0" />
      <mass value="0.0048487" />
      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
    </inertial>
    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
  </link>

  <joint name="caster_back_joint" type="continuous">
    <origin xyz="-0.080793 -0.00085033 -0.063942" rpy="0 0 0" />
    <parent link="base_link" />
    <child link="caster_back_link" />
    <axis xyz="0 0 1" />
  </joint>

  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
  <link name="caster_back_wheel_link">
    <inertial>
      <origin xyz="0 -1.1102E-16 -1.1102E-16" rpy="0 0 0" />
      <mass value="0.010151" />
      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
    </inertial>
    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
  </link>

  <joint name="caster_back_wheel_joint" type="continuous">
    <origin xyz="-0.0135 0.0002 -0.0166" rpy="0 0 0" />
    <parent link="caster_back_link" />
    <child link="caster_back_wheel_link" />
    <axis xyz="0 1 0" />
  </joint>


  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
  <link name="lidar_link">
    <inertial>
      <origin xyz="0 0 0" rpy="0 0 0" />
      <mass value="0.01" />
      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
    </inertial>
    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
  </link>

  <joint name="lidar_joint" type="fixed">
    <origin xyz="-0.0048872 0.000614 0.10238" rpy="0 0 0" />
    <parent link="base_link" />
    <child link="lidar_link" />
    <axis xyz="0 0 0" />
  </joint>

  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
<link name="imu_link">
  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
</link>

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
<joint name="imu_joint" type="fixed">
  <parent link="base_link"/> 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
  <child link="imu_link"/>
  <origin xyz="0 0 0.06" rpy="0 0 0"/> 
</joint>

</robot>

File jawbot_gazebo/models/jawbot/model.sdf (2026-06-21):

<?xml version="1.0" ?>
<sdf version="1.8">
  <model name="jawbot">
    <pose>0 0 0 0 0 0</pose> <link name="base_link">
      <pose>0 0 0.060292 0 0 0</pose>
      <inertial>
        <pose>0.00027838 0.00024581 -0.013572 0 0 0</pose>
        <mass>0.51707</mass>
        <inertia>
          <ixx>0.0010682</ixx>
          <ixy>-1.8529e-07</ixy>
          <ixz>8.343e-08</ixz>
          <iyy>0.0011009</iyy>
          <iyz>-2.7461e-07</iyz>
          <izz>0.0021554</izz>
        </inertia>
      </inertial>
      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
    </link>

    <link name="left_wheel_link">
      <pose>-0.00079275 0.0925 -0.00125 0 0 0</pose>
      <inertial>
        <pose>-3.7201e-08 -0.0056934 4.4552e-08 0 0 0</pose>
        <mass>0.033874</mass>
        <inertia>
          <ixx>1.2633e-05</ixx>
          <ixy>5.4997e-12</ixy>
          <ixz>2.0409e-10</ixz>
          <iyy>2.3297e-05</iyy>
          <iyz>-3.9859e-12</iyz>
          <izz>1.2634e-05</izz>
        </inertia>
      </inertial>
      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
    </link>

    <link name="right_wheel_link">
      <pose>-0.00079275 -0.095321 -0.00125 0 0 0</pose>
      <inertial>
        <pose>-3.0238e-09 0.0068146 -5.7962e-08 0 0 0</pose>
        <mass>0.033874</mass>
        <inertia>
          <ixx>1.2633e-05</ixx>
          <ixy>-2.0076e-12</ixy>
          <ixz>-5.7414e-10</ixz>
          <iyy>2.3297e-05</iyy>
          <iyz>-6.4887e-12</iyz>
          <izz>1.2633e-05</izz>
        </inertia>
      </inertial>
      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
    </link>

    <link name="caster_front_link">
      <pose>0.079207 -0.00085033 -0.00365 0 0 0</pose>
      <inertial>
        <pose>-0.0033534 0.00028383 -0.0012173 0 0 0</pose>
        <mass>0.0048487</mass>
        <inertia>
          <ixx>4.8663e-07</ixx>
          <ixy>6.9734e-13</ixy>
          <ixz>-4.0889e-08</ixz>
          <iyy>4.5501e-07</iyy>
          <iyz>-8.246e-13</iyz>
          <izz>7.829e-07</izz>
        </inertia>
      </inertial>
      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
    </link>

    <link name="caster_front_wheel_link">
      <pose>0.065707 -0.00065033 -0.02025 0 0 0</pose>
      <inertial>
        <pose>0 -1.1102e-16 0 0 0 0</pose>
        <mass>0.010151</mass>
        <inertia>
          <ixx>7.6476e-07</ixx>
          <ixy>5.6938e-22</ixy>
          <ixz>7.0301e-42</ixz>
          <iyy>1.1586e-06</iyy>
          <iyz>6.5843e-38</iyz>
          <izz>7.6476e-07</izz>
        </inertia>
      </inertial>
      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
    </link>

    <link name="caster_back_link">
      <pose>-0.080793 -0.00085033 -0.00365 0 0 0</pose>
      <inertial>
        <pose>-0.0033534 0.00028383 -0.0012173 0 0 0</pose>
        <mass>0.0048487</mass>
        <inertia>
          <ixx>4.8663e-07</ixx>
          <ixy>6.9734e-13</ixy>
          <ixz>-4.0889e-08</ixz>
          <iyy>4.5501e-07</iyy>
          <iyz>-8.246e-13</iyz>
          <izz>7.829e-07</izz>
        </inertia>
      </inertial>
      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
    </link>

    <link name="caster_back_wheel_link">
      <pose>-0.094293 -0.00065033 -0.02025 0 0 0</pose>
      <inertial>
        <pose>0 -1.1102e-16 -1.1102e-16 0 0 0</pose>
        <mass>0.010151</mass>
        <inertia>
          <ixx>7.6476e-07</ixx>
          <ixy>2.9657e-21</ixy>
          <ixz>7.0301e-42</ixz>
          <iyy>1.1586e-06</iyy>
          <iyz>-7.0484e-36</iyz>
          <izz>7.6476e-07</izz>
        </inertia>
      </inertial>
      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
    </link>

    <link name="lidar_link">
      <pose>-0.0048872 0.000614 0.162672 0 0 0</pose>
      <inertial>
        <pose>0 0 0 0 0 0</pose>
        <mass>0.01</mass>
        <inertia>
          <ixx>1e-5</ixx>
          <ixy>0</ixy>
          <ixz>0</ixz>
          <iyy>1e-5</iyy>
          <iyz>0</iyz>
          <izz>1e-5</izz>
        </inertia>
      </inertial>
      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

      <sensor type="gpu_lidar" name="jawbot_lidar">
        <pose>0 0 0 0 0 0</pose>
        <always_on>true</always_on>
        <visualize>true</visualize>
        <update_rate>10</update_rate>
        <topic>/model/jawbot/scan</topic>
        <ray>
          <scan>
            <horizontal>
              <samples>360</samples>
              <resolution>1</resolution>
              <min_angle>-3.1415926</min_angle>
              <max_angle>3.1415926</max_angle>
            </horizontal>
          </scan>
          <range>
            <min>0.12</min>
            <max>12.0</max>
            <resolution>0.01</resolution>
          </range>
        </ray>
      </sensor>
    </link>

    <joint name="left_wheel_joint" type="revolute">
      <parent>base_link</parent>
      <child>left_wheel_link</child>
      <axis>
        <xyz>0 1 0</xyz>
        <limit>
          <lower>-1e16</lower> <upper>1e16</upper>
        </limit>
      </axis>
    </joint>

    <joint name="right_wheel_joint" type="revolute">
      <parent>base_link</parent>
      <child>right_wheel_link</child>
      <axis>
        <xyz>0 1 0</xyz>
        <limit>
          <lower>-1e16</lower>
          <upper>1e16</upper>
        </limit>
      </axis>
    </joint>

    <joint name="caster_front_joint" type="revolute">
      <parent>base_link</parent>
      <child>caster_front_link</child>
      <axis>
        <xyz>0 0 1</xyz>
        <limit>
          <lower>-1e16</lower>
          <upper>1e16</upper>
        </limit>
      </axis>
    </joint>

    <joint name="caster_front_wheel_joint" type="revolute">
      <parent>caster_front_link</parent>
      <child>caster_front_wheel_link</child>
      <axis>
        <xyz>0 1 0</xyz>
        <limit>
          <lower>-1e16</lower>
          <upper>1e16</upper>
        </limit>
      </axis>
    </joint>

    <joint name="caster_back_joint" type="revolute">
      <parent>base_link</parent>
      <child>caster_back_link</child>
      <axis>
        <xyz>0 0 1</xyz>
        <limit>
          <lower>-1e16</lower>
          <upper>1e16</upper>
        </limit>
      </axis>
    </joint>

    <joint name="caster_back_wheel_joint" type="revolute">
      <parent>caster_back_link</parent>
      <child>caster_back_wheel_link</child>
      <axis>
        <xyz>0 1 0</xyz>
        <limit>
          <lower>-1e16</lower>
          <upper>1e16</upper>
        </limit>
      </axis>
    </joint>

    <joint name="lidar_joint" type="fixed">
      <parent>base_link</parent>
      <child>lidar_link</child>
    </joint>

    <plugin filename="gz-sim-diff-drive-system" name="gz::sim::systems::DiffDrive">
      <left_joint>left_wheel_joint</left_joint>
      <right_joint>right_wheel_joint</right_joint>
      <wheel_separation>0.1878</wheel_separation>
      <wheel_radius>0.060292</wheel_radius>
      <max_linear_acceleration>2.0</max_linear_acceleration>
      <max_angular_acceleration>3.0</max_angular_acceleration>
      
      <topic>/model/jawbot/cmd_vel</topic>
      <odom_topic>/model/jawbot/odometry</odom_topic>
      <tf_topic>/model/jawbot/tf</tf_topic>
      
      <frame_id>odom</frame_id>
      <child_frame_id>base_footprint</child_frame_id>
      <odom_publish_frequency>30</odom_publish_frequency>
    </plugin>

    <plugin filename="gz-sim-joint-state-publisher-system" name="gz::sim::systems::JointStatePublisher">
      <topic>/model/jawbot/joint_states</topic>
    </plugin>

  </model>
</sdf>

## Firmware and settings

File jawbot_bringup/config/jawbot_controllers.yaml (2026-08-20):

controller_manager:
  ros__parameters:
    update_rate: 50  # Must match the 50Hz loop we coded on your Pi Pico!
    use_sim_time: false

    joint_state_broadcaster:
      type: joint_state_broadcaster/JointStateBroadcaster

    jawbot_base_controller:
      type: diff_drive_controller/DiffDriveController

    imu_broadcaster:
      type: imu_sensor_broadcaster/IMUSensorBroadcaster

jawbot_base_controller:
  ros__parameters:
    left_wheel_names: ["left_wheel_joint"]
    right_wheel_names: ["right_wheel_joint"]

    # --- PHYSICAL ROBOT DIMENSIONS ---
    # You MUST measure these on your physical Jawbot in meters!
    wheel_separation: 0.17  # Distance between the center of the left and right wheel
    wheel_radius: 0.04     # Radius of the wheels
    enable_odom_tf: false
    
    # --- KINEMATIC LIMITS ---
    use_stamped_vel: false
    base_frame_id: base_footprint

    linear:
      x:
        has_velocity_limits: true
        max_velocity: 1.0     # m/s
        has_acceleration_limits: true
        max_acceleration: 1.0 # m/s^2
    angular:
      z:
        has_velocity_limits: true
        max_velocity: 2.0     # rad/s
        has_acceleration_limits: true
        max_acceleration: 2.0 # rad/s^2


imu_broadcaster:
  ros__parameters:
    sensor_name: "imu_sensor"
    frame_id: "imu_link"

    static_covariance_orientation: [-1.0, 0.0, 0.0, 0.0, 0.0, 0.0, 0.0, 0.0, 0.0]
    
    # Safe default noise thresholds
    static_covariance_angular_velocity: [0.001, 0.0, 0.0, 0.0, 0.001, 0.0, 0.0, 0.0, 0.001]
    static_covariance_linear_acceleration: [0.001, 0.0, 0.0, 0.0, 0.001, 0.0, 0.0, 0.0, 0.001]

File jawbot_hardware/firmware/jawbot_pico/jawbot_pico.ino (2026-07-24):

#include "L298n_motor_driver.h"
#include "WheelEncoder.h"
#include "pid.h"
#include "RobotJoint.h"
#include "SerialProtocol.h"

// --- NEW: IMU DRIVER ---
#include "gy87_driver.h"
#define USE_IMU  // Comment this line out to completely disable the IMU

#ifdef USE_IMU
    GY87 imu;
    IMUData imuData;
    bool imu_active = false;
#endif

// --- 1. HARDWARE MAPPING ---
L298N left_motor(6, 7, 13);
WheelEncoder left_enc(3, 2); 

L298N right_motor(12, 10, 11);
WheelEncoder right_enc(4, 5); // This confirms why we couldn't use GP4/5 for I2C!

// --- 2. INTERRUPT ROUTINES ---
void left_isr() { left_enc.handleInterrupt(); }
void right_isr() { right_enc.handleInterrupt(); }

// --- 3. SYSTEM CONSTANTS ---
const float TICKS_PER_REV = 988.0f;
const float TICKS_PER_RAD = TICKS_PER_REV / (2.0f * PI);
const float LOOP_HZ = 50.0f;
const float LOOP_DT = 1.0f / LOOP_HZ;

const int STATUS_LED = LED_BUILTIN; 
const uint32_t WATCHDOG_TIMEOUT_MS = 1000;

// --- 4. OBJECT INSTANTIATIONS ---
RobotJoint left_joint(left_motor, left_enc, PIDController(5.0, 0.055, 0.03, -100.0, 100.0));
RobotJoint right_joint(right_motor, right_enc, PIDController(5.0, 0.055, 0.03, -100.0, 100.0));
SerialProtocol ros2_comms(left_joint, right_joint);

// --- 5. TIMER SETUP ---
struct repeating_timer timer;
volatile bool run_control_cycle = false;

bool timer_callback(struct repeating_timer *t) {
    run_control_cycle = true;
    return true; 
}

// =========================================================

void setup() {
    Serial.begin(115200);
    
    pinMode(STATUS_LED, OUTPUT);
    left_joint.init();
    right_joint.init();

    // --- NEW: INITIALIZE IMU ---
    #ifdef USE_IMU
        if (imu.init()) {
            imu_active = true;
        } else {
            // Fails safely. If wiring breaks, the motors will still run!
            imu_active = false; 
        }
    #endif

    attachInterrupt(digitalPinToInterrupt(3), left_isr, CHANGE); 
    attachInterrupt(digitalPinToInterrupt(4), right_isr, CHANGE);

    add_repeating_timer_us(-20000, timer_callback, NULL, &timer);
}

void loop() {
    // 1. HARDWARE REAL-TIME LAYER (50Hz)
    if (run_control_cycle) {
        run_control_cycle = false;
        
        // Execute Motor PID
        left_joint.executeControlLoop(LOOP_DT, TICKS_PER_RAD);
        right_joint.executeControlLoop(LOOP_DT, TICKS_PER_RAD);

        // --- NEW: READ IMU ---
        #ifdef USE_IMU
            if (imu_active) {
                imu.update(imuData); // Pull fresh 50Hz data from the sensors
            }
        #endif

        // --- UPDATE REQUIRED HERE ---
        // You will need to modify your sendTelemetry function in SerialProtocol.h 
        // to accept the new imuData object so it can send it to the Pi.
        #ifdef USE_IMU
            ros2_comms.sendTelemetry(micros(), imuData, imu_active);
        #else
            ros2_comms.sendTelemetry(micros());
        #endif
    }

    // 2. BACKGROUND COMMUNICATION LAYER
    ros2_comms.processIncoming();

    // 3. WATCHDOG LED STATUS LAYER
    uint32_t current_time = millis();
    if (current_time - ros2_comms.getLastCommandTime() > WATCHDOG_TIMEOUT_MS) {
        // DISCONNECTED: Safety override to stop motors if ROS 2 crashes
        left_joint.setTargetVelocity(0.0);
        right_joint.setTargetVelocity(0.0);

        // Blink LED at 2Hz (toggle every 250ms) using math, not blocking delays
        if ((current_time / 250) % 2 == 0) {
            digitalWrite(STATUS_LED, HIGH);
        } else {
            digitalWrite(STATUS_LED, LOW);
        }
    } else {
        // CONNECTED: Solid Light
        digitalWrite(STATUS_LED, HIGH);
    }
}

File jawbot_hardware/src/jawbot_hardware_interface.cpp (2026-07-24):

#include "jawbot_hardware/jawbot_hardware_interface.hpp"
#include "hardware_interface/types/hardware_interface_type_values.hpp"
#include "pluginlib/class_list_macros.hpp"

namespace jawbot_hardware
{

hardware_interface::CallbackReturn JawbotHardwareInterface::on_init(const hardware_interface::HardwareInfo & info)
{
  if (hardware_interface::SystemInterface::on_init(info) != hardware_interface::CallbackReturn::SUCCESS) {
    return hardware_interface::CallbackReturn::ERROR;
  }

  // Parse custom parameters injected from the URDF <ros2_control> block
  port_ = info_.hardware_parameters["port"];
  baud_rate_ = std::stoi(info_.hardware_parameters["baud_rate"]);
  double ticks_per_rev = std::stod(info_.hardware_parameters["ticks_per_rev"]);
  ticks_per_rad_ = ticks_per_rev / (2.0 * M_PI);

  hw_positions_.resize(info_.joints.size(), std::numeric_limits<double>::quiet_NaN());
  hw_velocities_.resize(info_.joints.size(), std::numeric_limits<double>::quiet_NaN());
  hw_commands_.resize(info_.joints.size(), std::numeric_limits<double>::quiet_NaN());

  // ===============================================================
  // EMBEDDED DYNAMIC TUNING NODE
  // ===============================================================
  tune_node_ = std::make_shared<rclcpp::Node>("jawbot_pid_tuner");
  
  // Declare the parameters so rqt_reconfigure can see them
  tune_node_->declare_parameter("motor_kp", current_kp_);
  tune_node_->declare_parameter("motor_ki", current_ki_);
  tune_node_->declare_parameter("motor_kd", current_kd_);

  // Create a callback that fires EVERY TIME you move a slider in the GUI
  param_cb_ = tune_node_->add_on_set_parameters_callback(
    [this](const std::vector<rclcpp::Parameter> &parameters) {
      for (const auto &param : parameters) {
        if (param.get_name() == "motor_kp") current_kp_ = param.as_double();
        if (param.get_name() == "motor_ki") current_ki_ = param.as_double();
        if (param.get_name() == "motor_kd") current_kd_ = param.as_double();
      }

      // Pack the new values into the Phase 2 'p' string contract
      char buffer[64];
      snprintf(buffer, sizeof(buffer), "p %.3f %.3f %.3f\n", current_kp_, current_ki_, current_kd_);
      
      // Send it instantly to the Pi Pico
      if (serial_conn_.is_connected()) {
        serial_conn_.write_msg(std::string(buffer));
        RCLCPP_INFO(rclcpp::get_logger("JawbotHardware"), "Sent PID Update: %s", buffer);
      }

      rcl_interfaces::msg::SetParametersResult result;
      result.successful = true;
      return result;
    }
  );

  // Spin the node on a separate background thread so it doesn't block the real-time loop!
  tune_thread_ = std::thread([this]() {
    rclcpp::spin(tune_node_);
  });
  // ===============================================================

  return hardware_interface::CallbackReturn::SUCCESS;
}

std::vector<hardware_interface::StateInterface> JawbotHardwareInterface::export_state_interfaces()
{
  std::vector<hardware_interface::StateInterface> state_interfaces;
  for (uint i = 0; i < info_.joints.size(); i++) {
    state_interfaces.emplace_back(hardware_interface::StateInterface(info_.joints[i].name, hardware_interface::HW_IF_POSITION, &hw_positions_[i]));
    state_interfaces.emplace_back(hardware_interface::StateInterface(info_.joints[i].name, hardware_interface::HW_IF_VELOCITY, &hw_velocities_[i]));
  }

  // --- EXPORT IMU SENSOR STATES ---
  // The string "imu_sensor" must exactly match the name of the sensor in your URDF!
  state_interfaces.emplace_back(hardware_interface::StateInterface("imu_sensor", "linear_acceleration.x", &hw_imu_accel_[0]));
  state_interfaces.emplace_back(hardware_interface::StateInterface("imu_sensor", "linear_acceleration.y", &hw_imu_accel_[1]));
  state_interfaces.emplace_back(hardware_interface::StateInterface("imu_sensor", "linear_acceleration.z", &hw_imu_accel_[2]));

  state_interfaces.emplace_back(hardware_interface::StateInterface("imu_sensor", "angular_velocity.x", &hw_imu_gyro_[0]));
  state_interfaces.emplace_back(hardware_interface::StateInterface("imu_sensor", "angular_velocity.y", &hw_imu_gyro_[1]));
  state_interfaces.emplace_back(hardware_interface::StateInterface("imu_sensor", "angular_velocity.z", &hw_imu_gyro_[2]));

  state_interfaces.emplace_back(hardware_interface::StateInterface("imu_sensor", "orientation.x", &hw_imu_quat_[0]));
  state_interfaces.emplace_back(hardware_interface::StateInterface("imu_sensor", "orientation.y", &hw_imu_quat_[1]));
  state_interfaces.emplace_back(hardware_interface::StateInterface("imu_sensor", "orientation.z", &hw_imu_quat_[2]));
  state_interfaces.emplace_back(hardware_interface::StateInterface("imu_sensor", "orientation.w", &hw_imu_quat_[3]));
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

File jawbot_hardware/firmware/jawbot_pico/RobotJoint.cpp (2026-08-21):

#include "RobotJoint.h"
#include <cmath>

RobotJoint::RobotJoint(L298N& motor, WheelEncoder& encoder, PIDController pid)
    : motor_(motor), encoder_(encoder), pid_(pid), target_velocity_(0.0f), last_ticks_(0) {}

void RobotJoint::init() {
    motor_.init();
    encoder_.init();
}

void RobotJoint::setTargetVelocity(float rad_s) { 
    target_velocity_ = rad_s; 
}

void RobotJoint::updatePIDGains(float kp, float ki, float kd) { 
    pid_.setGains(kp, ki, kd); 
}

int32_t RobotJoint::readAbsoluteTicks() { 
    return encoder_.getTicks(); 
}

void RobotJoint::executeControlLoop(float dt, float ticks_per_rad) {
    int32_t current_ticks = encoder_.getTicks();
    int32_t delta_ticks = current_ticks - last_ticks_;
    last_ticks_ = current_ticks;

    // 1. Calculate actual angular velocity (rad/s)
    float actual_velocity = (static_cast<float>(delta_ticks) / ticks_per_rad) / dt;

    // 2. HARD STOP: Silent brake when command is zero
    if (std::fabs(target_velocity_) < 0.01f) {
        pid_.reset();
        motor_.setSpeed(0.0f);
        return;
    }

    // 3. Compute active PID feedback
    float pid_effort = pid_.compute(target_velocity_, actual_velocity, dt);

    // =====================================================================
    // 4. DUAL-STAGE FRICTION COMPENSATION & FEEDFORWARD
    // =====================================================================
    const float STATIC_BREAKAWAY = 38.0f; // Initial kick to overcome stiction
    const float KINETIC_ASSIST   = 33.0f; // Running assist once rolling
    const float KV_FEEDFORWARD   = 3.3f;  // Baseline voltage scaling

    // Taper boost once the wheel is rolling
    float active_offset = (std::fabs(actual_velocity) < 0.25f) ? STATIC_BREAKAWAY : KINETIC_ASSIST;

    float total_effort = (target_velocity_ * KV_FEEDFORWARD) + pid_effort;

    if (target_velocity_ > 0.0f) {
        total_effort += active_offset;
    } else if (target_velocity_ < 0.0f) {
        total_effort -= active_offset;
    }

    // Actuator safety limits (-100% to +100%)
    if (total_effort > 100.0f) total_effort = 100.0f;
    if (total_effort < -100.0f) total_effort = -100.0f;

    // 5. Command the L298N H-Bridge
    motor_.setSpeed(total_effort);
}

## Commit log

2026-06-21 Initialize jawbot packages: bringup, description, gazebo, hardware, and navigation
    [caster_back_link.STL, caster_back_wheel_link.STL, caster_front_link.STL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]
2026-06-21 Fix jawbot Gazebo URDF/SDF wheel alignment, caster clearance, and joint state TF bridge
    [caster_back_link.STL, caster_back_wheel_link.STL, caster_front_link.STL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]
2026-07-01 feat(hardware): introduce Raspberry Pi Pico firmware for closed-loop motor control
    - Implement L298N motor driver class for dual-motor control
    - Implement interrupt-driven quadrature wheel encoder class for precise feedback
    - Implement PID velocity control loop running at 50Hz (via hardware timer)
    - Implement SerialProtocol for message passing between Raspberry Pi Pico and ROS2
    - Add unified RobotJoint abstraction encapsulating motor, encoder, and PID controller
2026-07-01 feat: integrate ros2_control hardware interface and bringup configurations
    - Add hardware interface implementation (C++) and plugin configuration
    - Update Pico firmware with refined SerialProtocol
    - Introduce jawbot_ros2_control.urdf.xacro and link to main URDF
    - Implement ROS 2 launch files and configurations in jawbot_bringup
    - Update CMakeLists.txt and package.xml dependencies across packages
    [jawbot.urdf.xacro, jawbot_controllers.yaml, jawbot_ros2_control.urdf.xacro]
2026-07-10 Fix: Adjust the wheel diameter and the separation for the actual values
    [jawbot_controllers.yaml]
2026-07-10 Fix: add a deadband for wheel speed to enhance PID
    [RobotJoint.cpp]
2026-07-10 Feat: Add a PID Live tuner to tune the pid using rgtconfig
2026-07-10 docs: update deployment steps and document dynamic PID tuning
2026-07-10 Docs:Clarify steps to hardcode and save PID values
    Updated instructions for saving PID values in firmware and hardware interface files.
2026-07-19 feat: integrate GY-87 IMU into firmware and ROS 2 hardware interface
    [jawbot.urdf.xacro, jawbot_controllers.yaml, jawbot_ros2_control.urdf.xacro]
2026-07-23 fix: update motor encoder ticks_per_rev to 988
    [jawbot_ros2_control.urdf.xacro]
2026-07-23 feat: add linear calibration script
2026-07-23 tuned the pid values
2026-07-23 chore: tweak PID gains and add odometry calibration documentation
2026-07-24 feat: implement EKF localization and reorganize calibration docs
2026-07-24 fix(bringup): add static covariance params to imu_broadcaster
    [jawbot_controllers.yaml]
2026-07-24 fix(bringup): explicitly configure IMU state interfaces
    [jawbot_controllers.yaml]
2026-07-24 fix(bringup): export IMU orientation state interfaces and add default covariance
    [jawbot_controllers.yaml]
2026-07-24 fix(localization): update EKF base frame and sensor topics
2026-07-24 fix: update PID parameters and set orientation covariance to -1.0 in imu_broadcaster
    [jawbot_hardware_interface.hpp, jawbot_pico.ino]
2026-07-24 docs: add EKF calibration guide
2026-08-20 fix(mapping): tune SLAM and save room map
    [jawbot_controllers.yaml]
2026-08-21 feat(firmware): implement dual-stage friction compensation and feedforward control in RobotJoint
2026-08-21 docs: add NAV2 calibration guide and update Control_Arc and README for Nav2/AMCL integration
